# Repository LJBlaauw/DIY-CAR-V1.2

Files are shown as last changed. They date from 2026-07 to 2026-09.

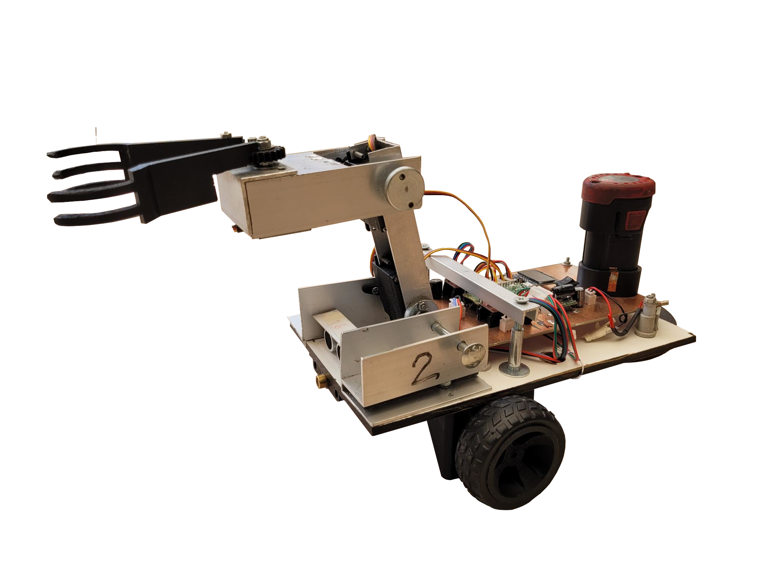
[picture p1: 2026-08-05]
hardware/Robot_carv1.1.png

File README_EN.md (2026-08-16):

# DIY Robot CAR

**This project started with my brother-in-law's idea to make a robot cart**
I have a background in electronics development (microcontrollers, power electronics and audio).
This was unknown territory for my brother-in-law, so as often happens, I offered my help.
Open source software was used for development. As OS I used Linux Fedora 44 desktop KDE plasma.
The challenge is to have the cart carry out these actions autonomously, especially the real-time nature of this is a challenge.
First we built everything on a breadboard. This was not very successful because the wiring often did not provide reliable connections.
Also the choice of the type of stepper motor (unipolar) and servos was inadequate (too light, too much mechanical play)
So version zero has been updated to version 1 with bipolar stepper motors and drivers, MG996 servos with metal gears.
To assemble this, various parts were 3D printed.
In version 1, most of the mechanics were made of sheet material and aluminum profiles.
In version 2 an electronic compass and acceleration sensor have been added. The gripper has also been fundamentally changed and has been 3D printed as much as possible.

The first questions that had to be answered were:
1. What is the scope of the project (what should the robot cart do)
2. What is readily available online
3. What materials are we going to use (motors and sensors)
4. What kind of software are we going to use to make the control possible.
5. presentation of status and measurement data
6. Develop tools and environment
 
1. **Scope: The robot cart must autonomously search for a light source and pick up an object there and bring it to the starting point**

2. **availability:**
1. We could find everything at various hobby stores, Amazon and Aliexpress.
 
3. **Materials**
1. *Motors:*
1. Two independently controllable stepper motors for locomotion.
2. Three independently controllable servo motors for the robot arm and gripper.
*Sensors:*
1. Ultrasonic sensor to measure the distance from the cart to the object.
2. Two light sensitive resistors to find the direction of the light source.
3. We chose the RP2040 of Raspberry Pi as the microcontroller, in version 2 the RP2350W.
4. Optional compass/acceleration sensor.
5. Optionally a WiFi connection with a web socket to read sensor data and issue commands.
    
4. **Programming language**
For the programming language we chose Micropython, which is easier to learn than C/C++.
The advantage is that no translation is required and many ready-made library components are built-in.
To get a good real-time working system there are a number of challenges.
Since Micropython is an interpreter, it runs a factor of 100 slower than C.
There are a number of options to optimize the real-time properties.
1. Using the PIO state machines integrated into the microcontroller.
2. Divide the Software modules (workload) over the two CPU cores
3. Possibly use cooperative multitasking (asyncio).
    
5. **Presentation**
As a presentation, we have a multi-color LED and an OLED display of 128x64 dots as a status message.
With version two we opted for the RP2350W. This has 2 M33 instead of the M0 cores.
With this processor update, calculating the compass/gear is much faster, and
remote control/reading is also possible with a web socket.
There are also two LEDs that signal 5V and 3.3V.
The REPL of the IDE tools is also present to display information with print commands.
    
6. **Development tools**
To design and produce the printed circuit board for electronics I use:
1. Schematic and layout: KiCAD (now version 10.4), FlatCAM Gerber to Gcode, CNC machine an upgraded 3018 with GRBLHAL controller.
2. Mechanical design: FreeCAD for 3D parametric models and a Prusa MK4 3D printer.
3. Software development environment: IDE VSCODE with micropico extension and AI claude 4.6 chat.
4. Thonny IDE simpler development environment than VSCODE.

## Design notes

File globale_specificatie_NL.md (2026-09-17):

# DIY Robot Car — MicroPython op RP2350 (Pico 2 W)

## Systeembeschrijving

Een autonoom rijdend robotkarretje dat een lichtbron opzoekt, ernaartoe rijdt, met een grijparm een voorwerp oppakt en daarna naar de beginpositie terugkeert.

### Status van waarden

In dit document worden ontwerpwaarden waar nodig als volgt aangeduid:

- **[GEMETEN]** — rechtstreeks op de huidige robot/hardware gemeten.
- **[BEREKEND]** — afgeleid uit gemeten waarden, datasheetwaarden of softwareconstanten.
- **[AANNAME]** — gebruikt in het ontwerpmodel, maar nog niet voldoende gemeten.
- **[TE VERIFIËREN]** — hardware- of softwaregedrag dat nog expliciet getest moet worden.

Een hoge numerieke resolutie is niet automatisch dezelfde grootheid als fysieke nauwkeurigheid. Wielslip, bandvervorming, sensorbias, mechanische speling en kalibratie blijven afzonderlijke foutbronnen.

### Werkvolgorde

1. **LDR-scan** — Draai in één richting een volledige omwenteling + overlap (**370°**) en meet lichtsterkte met twee gepaarde LDR's. Een volledige omwenteling bevat altijd het maximum; de 10° overlap voorkomt dat een piek rond 0°/360° op de rand valt. Er is dus géén pre-roll (terugdraaien vóór de scan) meer nodig.
2. **Uitlijnen** — Draai naar de gevonden richting via de **kortste weg** (door- of terugdraaien, afhankelijk van welke hoek kleiner is). De laatste graden worden altijd in dezelfde richting benaderd zodat de speling/backlash constant blijft. De eindpositie wordt closed-loop bijgeregeld via de LDR's (zie hieronder). Daarmee worden hoek-/uitlijnfouten door gemiste stappen of mechanische afwijking gecorrigeerd; dit is geen detectie of correctie van algemene lineaire wielslip.
3. **Rijden met LDR-correctie** — Rij naar de lichtbron en corrigeer onderweg continu op koersafwijking: zolang er een verschil tussen de twee LDR-waarden (na gain-correctie) optreedt, stuurt de kar bij richting de helderste kant tot A ≈ B. Stop op ingestelde afstand via de ultrasoonsensor (draait onafhankelijk in de achtergrond, SM4).
4. **Grijpen** — Bestuur twee scharnier-servo's zodat de arm het voorwerp bereikt.
5. **Sluiten grijper** — Servo 4 met stroombeperking (PI-limiter) zodat de servo niet overbelast raakt.
6. **Terugkeren** — Omdraaien en via opgeslagen wielodometrie/trajectinformatie terug naar de startpositie; voorwerp neerzetten. De nauwkeurigheid hiervan wordt begrensd door cumulatieve odometriefout en wielslip.
7. **GY9250-ondersteuning** — gyro en magnetometer kunnen de oriëntatie/koers ondersteunen. Ze leveren geen absolute X/Y-positie. Software is aanwezig, maar integratie en hardwarekalibratie zijn nog niet gevalideerd.

---

## Hardware

| Component | Aantal | Type | Aansluiting |
|---|---|---|---|
| Stappenmotor | 2 | — | Driver: TMC2209 |
| Servomotor (arm) | 2 | MG996R | GPIO2, GPIO3 |
| Servomotor (grijper) | 1 | MG996R | GPIO22 — met stroomsensor |
| Servomotor (optioneel/reserve) | 1 | MG996R | GPIO4 — bedraad op PCB, nog niet aangesloten/geïmplementeerd |
| Ultrasoonsensor | 1 | RCWL-1601 | GPIO19 (Echo), GPIO20 (Trig) |
| LDR | 2 | 10 kΩ spanningsdeler (pull-up naar 3V3) | GPIO26, GPIO27 |
| Laser (kruishaar) | 1 | — | GPIO15 via MOSFET |
| OLED | 1 | SSD1306 | I2C0: SDA=GPIO0, SCL=GPIO1 |
| Gyroscoop/kompas | 1 | GY9250 | I2C1: SDA=GPIO10, SCL=GPIO11 — *software aanwezig (`lib/GY9250`, fusie, stepper-koppeling); integratie en hardwarekalibratie nog niet gevalideerd* |
| Stroomsensor grijper | — | 0,1 Ω shunt + opamp (gain 14×) | ADC2 = GPIO28 |
| LED | 1 | WS2812B | GPIO6 |
| WiFi/Bluetooth | 1 | Infineon CYW43439 (onboard Pico 2 W) | interne boardverbinding |

De robotcontroller is een **Raspberry Pi Pico 2 W** met een **RP2350** microcontroller en een onboard **Infineon CYW43439** wireless controller. In MicroPython wordt deze via de CYW43-driver aangestuurd. De webserver/websocket-besturing gebruikt WiFi; de geplande softwarearchitectuur houdt netwerk- en hoofdcontroltaken op core 0 en reserveert core 1 voor GY9250/displaytaken. Deze coreverdeling moet nog als geheel op hardware worden gevalideerd.

Zie [hardware/gpio_pinout.md](hardware/gpio_pinout.md) voor de volledige GPIO-tabel en verificatiestatus.

### Ontwikkelomgeving

| Onderdeel | Configuratie |
|---|---|
| Robotboard | Raspberry Pi Pico 2 W |
| Microcontroller | RP2350 |
| Robotfirmware | MicroPython voor Pico 2 W — **exacte versie/build nog vastleggen** |
| Ontwikkel-PC | Fedora Linux 44 |
| Desktop | KDE Plasma |
| PC-tests | CPython; pure-Python tests uit `tests/` |
| Hardwarevalidatie | logic analyzer voor PIO/STEP-timing; multimeter/meetopstelling voor voeding en sensorkalibratie |

> **[TE VERIFIËREN] Reproduceerbaarheid:** leg vóór de definitieve hardwaretest de exacte MicroPython-versie/build en de gebruikte CPython-versie vast. De software gebruikt RP2350-specifieke voorzieningen zoals PIO2 en `rp2.DMA()`.

---

## Software modules

### PIO State Machine toewijzing

| SM | Module | Functie |
|---|---|---|
| SM0 | stepper/stepper.py *of* stepper_ramp.py | Stapgenerator motor A |
| SM1 | stepper/stepper.py *of* stepper_ramp.py | Stapgenerator motor B |
| SM2 | stepper/stepper.py *of* stepper_ramp.py | Stapenteller motor A |
| SM3 | stepper/stepper.py *of* stepper_ramp.py | Stapenteller motor B |
| SM4 | ultrasoon/ultrasoon.py | Ultrasoonsensor trigger + echometing |
| SM8 | LDR/ldr_scan_isr.py | Variabele klok voor LDR-sampletiming (PIO2 SM0) |

PIO0 is hiermee vol (4 van 4 SM's). `stepper.py` en `stepper_ramp.py` zijn **alternatieven** — ze claimen dezelfde SM's en dezelfde GPIO's, dus importeer er altijd maar één.

### DMA-kanaaltoewijzing

| Kanaal | Module | Functie |
|---|---|---|
| 2 stuks (dynamisch geclaimd via `rp2.DMA()`) | stepper/stepper_ramp.py | Rampatabel → TX-FIFO van SM0 / SM1 |

De RP2350 heeft 16 DMA-kanalen; `treq_sel = (pio_num << 3) + sm_num` (klopt ook op RP2350, `DREQ_PIO2_TX0 = 16`).

---

### `lib/stepper/stepper.py`

Dual stappenmotor controller op basis van PIO. Beide motoren lopen onafhankelijk via eigen SM en teller-SM.

**Constanten:**
- **[GEMETEN]** `WHEEL_CIRC = 19,1 cm` — wielomtrek. Was 20,94 cm; die waarde gaf **8,8 % te korte afstanden** (50 cm gecommandeerd → 45,6 cm gereden). De belaste rolomtrek van een rubberwiel is iets kleiner dan de vrije omtrek, dus deze waarde nog kalibreren (zie *Odometriekalibratie* hieronder).
- **[GEMETEN]** `TRACK_WIDTH = 13,6 cm` — geometrische spoorbreedte hart-op-hart. Nodig voor elke rotatie- en koersberekening.
- `STEPS_REV = 12800` — stappen per omwenteling (**1/64 microstepping**, TMC2209: 200 volle stappen × 64). MS-pinnen hardwired: **MS1 → GND, MS2 → VCC_IO** *(in de huidige documentatie als +5 V aangegeven; fysiek verifiëren)* (zie [hardware/gpio_pinout.md](hardware/gpio_pinout.md)).
- **[BEREKEND]** `CM_PER_STEP ≈ 14,9 µm/stap`
- **[BEREKEND]** `STEPS_PER_DEG ≈ 159` — stappenverschil tussen de wielen per graad koersverandering. Resolutie dus **0,0063°**.
- **[BEREKEND/CONFIG]** `F_PIO = 15 MHz` — 150 MHz sysclk / 10, dus een **integer klokdeler** (geen jitter van de fractionele deler). `speed_to_delay()` geeft bij de topsnelheid van 12800 stappen/s de waarde **576**. De delaylus van déze PIO is twee instructies (`nop().side(0)` + `jmp(y_dec)`), dus elke eenheid is 2 cycles en de **snelheidsresolutie is 0,17 %**. De STEP-puls blijft 11 cycles = **733 ns**, ruim boven het TMC2209-minimum van ~100 ns.
  > De vaak genoemde 1167 cycles en 0,085 % horen **niet** hier maar bij `_delay_for()` in `stepper_ramp.py`, waar de delaylus één cycle per eenheid is. Verwissel die twee niet.

> **`OVERHEAD` in `speed_to_delay()`:** blijft op de op hardware gemeten 9. De PIO-lus kost werkelijk 13 cycles vaste overhead terwijl de formule er 18 aanneemt; bij 15 MHz zakt die **systematische** afwijking bij topsnelheid automatisch van ~2,3 % naar ~0,43 %, dus hermeten is niet meer nodig. (Eerder stond hier ~11 %; dat was te hoog ingeschat.) Daar komt nog de afkapping van `int()` bij, maximaal 2 cycles ≈ 0,17 %.

**Publieke functies:**

| Functie | Beschrijving |
|---|---|
| `mov(dir, speed, dist)` | Beide motoren gelijktijdig. `dir='f'/'b'`, speed in cm/s, dist in cm |
| `s1(dir, speed, dist)` | Alleen motor A |
| `s2(dir, speed, dist)` | Alleen motor B |
| `rotate(dir, speed, dist)` | Draai op de as. `dir='l'/'r'`, dist in cm (booglengte wiel) |
| `stop()` | Stop beide SM's direct |
| `enable()` / `disable()` | Zet driver-enable aan/uit |
| `status()` | Print positie en status van beide motoren |
| `distance()` | Print en geef PIO-stapafstand terug (cm) |
| `reset_PIO_distance()` | Reset hardware-tellers naar nul |
| `pio_pos1()` / `pio_pos2()` | Lees aantal stapjes motor A/B uit PIO |

**Werking stapgenerator (PIO):**
- `pull(noblock)` haalt een delay-waarde uit de TX FIFO (of hergebruikt de vorige).
- De delay bepaalt de stapfrequentie → snelheid.
- De teller-SM telt STEP-flanken en genereert een IRQ als het doel bereikt is.
- IRQ-handler stopt de bijbehorende motor-SM en werkt de softwarepositie bij.

**Beperking:** er is geen ramp. De snelheid wordt in één keer gecommandeerd, dus vanuit stilstand moet de rotor binnen één microstap (78 µs) naar de eindsnelheid springen. Dat is een oneindige versnelling: de rotor kan het veld niet volgen, verliest synchronisme en de motor blijft zoemend staan. Dit is een **synchronisme-fout, geen koppel-fout** — zie de koppelbegroting hieronder. `stepper_ramp.py` of `stepper_rmp.py`lost dit op.

---

### `lib/stepper/stepper_rmp.py`

Dual stappenmotor controller **met ramp** (PIO + DMA) zelfde functie als `stepper.py` maar nu met ramp.

### `lib/stepper/stepper_ramp.py`

Dual stappenmotor controller **met ramp** (PIO + DMA) en doorlopende koerscorrectie. Vervangt `stepper.py`.

Het is een **API-grotendeels compatibele opvolger, geen drop-in replacement.** De namen `mov`, `s1`, `s2`, `rotate`, `stop`, `enable`, `disable`, `status`, `distance`, `pio_pos1/2` en `reset_PIO_distance` bestaan nog met dezelfde betekenis, maar bij migratie zijn dit de breekpunten:

| Verschil | Gevolg |
|---|---|
| Geen globale `sm0`..`sm3` meer | code die daar direct aan komt, breekt |
| De generator-SM's blijven **permanent actief** en stallen op een lege FIFO | wachten op `sm0.active()` werkt niet meer; gebruik `busy()` |
| `distance()` print niets en geeft **één signed middenafstand** i.p.v. twee motorafstanden | aanroepers die twee waarden uitpakken, breken |
| De bewegingsfuncties geven `True`/`False` i.p.v. impliciet `None` | alleen relevant als de returnwaarde gebruikt werd |
| Andere stop- en voltooiingssemantiek | `halt()` / `brake()` / `emergency_stop()` zijn nu drie verschillende dingen |
| `reset_PIO_distance()` weigert tijdens een beweging | roep eerst `halt()` of `brake()` aan |
| Ongeldige invoer geeft `ValueError` i.p.v. stil door te rekenen | een negatieve `dist` werd eerder stil positief gemaakt |

#### Ontwerpbasis

| Grootheid | Waarde |
|---|---|
| Massa kar | **[GEMETEN]** 1636 g |
| Wielomtrek / -radius | **[GEMETEN/BEREKEND]** 19,1 cm / 3,04 cm |
| Spoorbreedte (hart-op-hart) | **[GEMETEN]** 13,6 cm geometrisch |
| Motor | 17HS8401 — NEMA 17, 1,7 A, 52 N·cm, 1,8 Ω, 3,2 mH, rotor 68 g·cm² |
| Driver | TMC2209, standalone, **stealthChop**, 1/64 microstepping |
| VREF / motorstroom | **[BEREKEND, TE VERIFIËREN]** 1,0 V → ca. **0,71 A RMS** volgens huidige driveraannames; controleer sense-resistor/driveruitvoering |
| Motorspanning | 24 V (6S Li-ion, 25,2 V vol → ~18 V leeg) |
| Bereik snelheid | **[ONTWERPWAARDE, TE VERIFIËREN]** start 0,1 omw/s = 1,91 cm/s · max 1,0 omw/s = 19,1 cm/s |

**Koppelbegroting [BEREKEND]** — deze begroting ondersteunt de keuze voor een ramp en laat op papier ruime koppelmarge zien; de werkelijke marge moet met de huidige motorstroom en belasting op hardware worden bevestigd:

| Post | Koppel per wiel |
|---|---|
| Versnellen van 1636 g bij 55 cm/s² | 1,37 N·cm |
| Rotor-inertie (68 g·cm²) | 0,013 N·cm |
| Rolweerstand (ruim geschat) | ~1,2 N·cm |
| **Totaal nodig** | **~2,6 N·cm** |
| **Beschikbaar bij VREF 1 V** | **~22 N·cm** → factor 8 marge |

De post "versnellen" is `m·a/2 × r` = 1,636 kg × 0,55 m/s² ÷ 2 wielen × 0,0304 m; de eigen traagheid van de wielen zit er nog niet in, maar die is bij deze marge niet interessant.

Bij 22 N·cm en wielradius 3,04 cm is de trekkracht 7,2 N per wiel (14,5 N totaal) tegen een gewicht van 16,1 N: de **wielen slippen eerder dan dat de motor koppel tekortkomt**. Daarom is VREF = 1,0 V voorlopig een passende ontwerpinstelling (1,8 W dissipatie i.p.v. 10,4 W bij vol stroom). stealthChop volstaat: het praktische plafond is ~300 rpm en de kar draait op 60 rpm. De SPREAD-pin hoeft niet verbonden te worden.

#### FIFO-woordformaat

Elk 32-bit woord in de TX-FIFO codeert een heel **segment** in plaats van één stap:

| Bits | Inhoud |
|---|---|
| 15..0 | aantal stappen in dit segment − 1 (max 65536) |
| 31..16 | delay per stap in PIO-cycles (max 65535) |

Daardoor kost een ramp van 2200 stappen maar 256 woorden = **1 kB**. Eén 32-bit woord per stap zou 2200 × 4 = **8800 bytes ≈ 8,6 KiB per ramp** kosten. Vier losse tabellen (op/af voor twee motoren) zouden samen ongeveer **34,4 KiB** vragen, exclusief Python-objectoverhead. Segmentcodering reduceert dit sterk. Een kruisfase tot **97,8 cm** past in één enkel woord.

De PIO-lus is 7 instructies; vaste overhead **5 cycles per stap** (0,43 % bij topsnelheid).

#### Fasen van een beweging

| Fase | Bron | CPU-kosten |
|---|---|---|
| Ramp op | DMA-tabel, 256 woorden | **0** — segmenten van ~2 ms zijn te snel voor MicroPython; DMA is hier vereist en immuun voor GC-pauzes |
| Kruisfase **zonder** bijsturing | zelfde DMA-transfer, 1 woord | **0** |
| Kruisfase **met** bijsturing | CPU pusht 1 woord per 20 ms per motor | ~0,1 % (≈100 `put()`/s) |
| Ramp af | DMA-tabel, 256 woorden | **0** |

Een complete beweging van 50 cm zonder bijsturing is **513 woorden = 2052 bytes in één DMA-transfer** — hetzelfde nul-overhead gedrag als het oude concept, mét ramp. Er is daarbij **geen interrupt**: `stepper_ramp.py` configureert nergens een DMA- of PIO-IRQ. Tijdens de uitvoering doet de CPU niets, en voltooiing wordt gepolld met `busy()`. (De oude `stepper.py` hierboven had wél `sm2.irq`/`sm3.irq`.)

**Bij een lege FIFO stalt `pull(block)` met STEP laag.** Gevolgen:
- de motor houdt zijn positie, er gaat geen stap verloren;
- CPU-latency (ook een GC-pauze van tientallen ms) beïnvloedt de **staptiming niet** — de PIO genereert met hardware-precisie. Te late CPU betekent dat de correctie één slice later komt, geen timingfout;
- loopt de FIFO écht leeg, dan is het gevolg een korte pauze, geen glitch. Dit is netjes degraderend faalgedrag, in tegenstelling tot een CPU-getimede pulsgenerator.

Met 3 slices vooruit in de FIFO is de runway **60 ms** en de regellatentie eveneens ≤60 ms.

**DMA en CPU mogen nooit gelijktijdig in dezelfde FIFO schrijven** — de volgorde zou door elkaar lopen en de twee motoren konden verschillende segmentvolgordes krijgen, waarmee de ramp én de koers onbetrouwbaar worden. Daarom:

- tijdens de opramp pusht de CPU niets; `Move.service()` wacht tot `dma.active()` van **beide** motoren `False` is. De DMA is dan gestopt met *schrijven* terwijl de FIFO nog data bevat — precies de voorsprong die de CPU nodig heeft.
- de ramp-af-DMA wordt pas gestart nadat de CPU is gestopt met pushen.

> Wachten tot de rampstappen ook *uitgevoerd* zijn zou fout zijn: dan loopt de FIFO leeg en pauzeert de motor tussen ramp en kruisfase.

**Brugsegment.** Als de opramp-DMA klaar is met schrijven staan er nog maximaal 4 woorden in de FIFO. Aan het eind van de ramp zitten we op topsnelheid, dus die 4 woorden zijn samen maar ~3 ms — met `service()` elke 10 ms zou de FIFO alsnog leeglopen. Daarom eindigt de opramptabel met één **brugsegment** op kruissnelheid van `BRIDGE_SLICES × SLICE_MS` = 40 ms. Die stappen horen bij de kruisfase maar worden niet bijgestuurd; een correctie 40 ms eerder of later maakt niets uit.

**S-curve:** de snelheid volgt een smoothstep (3p²−2p³) in de afgelegde weg, dus de versnelling is nul aan begin én eind van de ramp — geen koppelschok op de overgangen. Kost niets extra, want de tabel wordt in Python gegenereerd en daarna alleen door DMA afgespeeld. `ACCEL_CM_S2 = 55` bepaalt de ramp-*afstand* (3,28 cm); de piekversnelling is 1,5× = 82 cm/s² = 0,084 g en de ramp *duurt* 0,55 s.

Een beweging korter dan 2 × 3,28 = 6,6 cm haalt de topsnelheid niet en krijgt automatisch een driehoekig profiel.

#### Exacte afstand

Bijsturen verandert **wanneer** stappen komen, niet **hoeveel**. Per motor wordt `committed` bijgehouden: de som van alle weggeschreven `repeat`-waarden. Het afremmpunt wordt op `committed` bepaald, niet op een gemeten positie, dus het **gecommandeerde gemiddelde stappentotaal is exact** — onafhankelijk van wanneer de regellus toevallig aanroept. De *fysieke* afstand is dat niet: microstepping-nauwkeurigheid, wielslip, bandvervorming en de kalibratie van `WHEEL_CIRC` komen daar nog overheen. Per slice geldt `repeat_A + repeat_B = 2 × base`, waardoor het midden van de kar precies `base` stappen opschuift terwijl het verschil de koers verandert.

Beide motoren krijgen per slice dezelfde slice-**duur** (20 ms) en een verschillend stappenaantal; daardoor blijven ze in de tijd synchroon (**berekende** afrondingsfout < 20 µs op 20 ms; nog niet met een logic analyzer nagemeten).

#### Odometrie — signed, want de teller-SM kent de DIR-pin niet

De teller-SM's tellen **STEP-flanken** en weten niets van de richting. Een ruwe pulsteller is daarom géén positie: bij een rotatie op de plaats lopen beide tellers positief op terwijl de wielen tegengesteld draaien. Elke motor houdt daarom naast de monotone pulsteller een **signed positie** bij die bij elke richtingswisseling het teken meeneemt.

| Functie | Betekenis |
|---|---|
| `pio_pos1()` / `pio_pos2()` | monotone pulsteller (ongesigneerd), gebruikt door `busy()` |
| `_Motor.travel()` | signed positie in stappen: vooruit positief, achteruit negatief |
| `distance()` | `(travel_A + travel_B) / 2 × CM_PER_STEP` — een rotatie geeft ~0 cm, achteruit telt negatief |
| `heading()` | `(travel_A − travel_B) / STEPS_PER_DEG` — werkt ook bij een rotatie op de plaats |

> **Let op:** de tellers tellen STEP-pulsen/commando's, geen gegarandeerde fysieke wielverplaatsing. Bij slip of een gemiste motorstap kan de odometrie dus afwijken. De GY9250 levert een onafhankelijke meting van draaisnelheid en oriëntatie, maar geen absolute lineaire X/Y-positie; lineaire slip van beide wielen vraagt een externe positiereferentie om rechtstreeks te detecteren.

#### Koerscorrectie — cascade LDR + gyro

Koersverandering komt van een **verschil in stappenaantal** tussen de wielen. Bij fire-and-forget, waar beide motoren aan hetzelfde totaal vastzitten, geeft een snelheidsverschil netto **nul** koersverandering (de kar maakt een boog en komt in dezelfde richting terug). In de kruisfase ligt dat totaal niet vast, dus daar integreert een snelheidsverschil wél tot een blijvende koersverandering.

| Lus | Sensor | Frequentie | Rol |
|---|---|---|---|
| Buiten | LDR A/B-verschil | enkele Hz (1× per 5 slices) | bepaalt **waar** we heen moeten; A ≈ B = recht op de bron. Levert het setpoint voor de draaisnelheid |
| Binnen | GY9250 gyro-Z | elke slice (~50 Hz) | onderdrukt **storingen**: hobbels, gleuven, ongelijke vloer, wielslip. Regelt het verschil tussen gewenste en gemeten draaisnelheid weg |

Dit is **geen dubbele besturing**: de LDR bepaalt de richting, de gyro alleen de storingsonderdrukking.

Let op wat de binnenlus wél en niet doet. Hij regelt het verschil tussen gewenste en gemeten **draaisnelheid** weg, dus hij dempt een verstoring *zolang die plaatsvindt*. Hij integreert geen hoekfout, dus de verdraaiing die er onderaan de streep uit komt wordt daarna niet teruggedraaid; de LDR-buitenlus doet dat. Zonder LDR (`damp_yaw_rate()`) is er dus **geen koershouden** — alleen demping, met bovendien blijvende drift door gyrobias. Bij een kortdurend afgedekte lichtbron blijft de kar daarom ongeveer rechtdoor gaan, maar hij komt niet op de oude koers terug.

De **magnetometer/kompas** wordt tijdens het rijden expres níet gebruikt — de stappenmotoren verstoren het veld (zie de GY9250-stappenmotorkalibratie). Het kompas is voor de terugweg, waar een absolute koers nodig is.

De **acceleratiemeter** wordt níet voor slipdetectie gebruikt. Dat idee — "stappen zonder versnelling betekent slip" — werkt niet: bij constante snelheid is de voorwaartse versnelling per definitie nul, dus normaal rijden en volledig doorslippen zien er identiek uit.

Wat er wél in zit is een **koersvolgfout** op gyro-Z: wijkt de gemeten draaisnelheid aanhoudend af van wat er werkelijk is weggeschreven, dan staat `HeadingController.yaw_tracking_error` op `True`. Dat is een *aanwijzing*, geen slipbewijs — regeldynamiek, gyrovertraging, verzadiging en een verkeerde gain geven hetzelfde beeld. Lineaire slip (beide wielen recht vooruit) is er sowieso niet mee te zien; dat vraagt een externe positiereferentie.

**Stuurgezag:** bij een snelheidsdifferentie van ±20 % is de draaisnelheid ±32 °/s; bij ±5 % is dat ±8 °/s. Resolutie 0,0063° (1 stap verschil). Die 32 °/s geldt **bij topsnelheid**: het gezag is een fractie van de rijsnelheid en schaalt dus evenredig mee (bij 5 cm/s nog 8,4 °/s). `turn_authority_deg_s(rate)` rekent dat uit en `Move()` zet er het plafond van de `HeadingController` mee.

#### Waarom niet de PIO-klok variëren

Het alternatief — `SMn_CLKDIV` tijdens runtime wijzigen — is bewust **niet** gebruikt, ook al is het technisch mogelijk via `machine.mem32`:
- het zit buiten het datapad, dus niet synchroon met de segmentgrenzen;
- de stappenaantallen zijn dan niet meer exact bekend;
- de delay-waarden staan in PIO-cycles, dus een klokwijziging herschaalt de rampatabel onderweg (en de versnelling schaalt met f²).

Als globale **snelheids-override** (alles langzamer, bv. bij een obstakel) blijft de klokdeler wel bruikbaar.

#### Publieke API

| Functie | Beschrijving |
|---|---|
| `mov(dir, speed, dist)` | Beide motoren, fire-and-forget mét ramp, nul CPU-overhead |
| `s1(dir, speed, dist)` / `s2(...)` | Idem, één motor |
| `rotate(dir, speed, dist)` | Draai op de as, `dist` = booglengte per wiel in cm |
| `rotate_deg(graden, speed)` | Draai op de as over een hoek. Positief = rechts |
| `drive(dist, speed, correction=fn)` | Beweging **met** doorlopende bijsturing; geeft een `Move` terug |
| `adrive(...)` | asyncio-variant van `drive()` |
| `Move.service()` | Vul de FIFO's bij en pas de correctie toe. ≥1× per 10 ms aanroepen. `False` = klaar |
| `Move.finish()` | Breek de beweging af en rem netjes af — ook tijdens de opramp, waar eerst de lopende DMA transactioneel wordt gewist en daarna vanaf de wérkelijke snelheid wordt afgeremd |
| `HeadingController(ldr_diff, gyro_rate)` | Cascade-koersregelaar. Geef de **controller zelf** mee aan `correction=`: dan zet `Move()` zijn stuurgezag op de werkelijke rijsnelheid en krijgt hij terugkoppeling over wat er is weggeschreven |
| `gyro_z_deg_s(sensor, sign=None)` | **Vereist** rond de GY9250: de driver levert radialen/s, de regelaar rekent in graden/s. Past `GYRO_Z_SIGN` toe |
| `damp_yaw_rate(gyro_rate)` | Demping van de draaisnelheid op alleen de gyro. **Houdt geen koers vast** — heette daarom eerder ten onrechte `hold_heading()`; zie de cascade-uitleg hierboven |
| `turn_authority_deg_s(rate)` | Maximale draaisnelheid bij een gegeven rijsnelheid |
| `halt()` (= `stop()`) | Onmiddellijke stop, drivers blijven **aan**: de motoren houden hun positie. Dit is het gedrag van `stepper.stop()` |
| `brake()` | Nette stop: remt af vanaf de **geschatte** huidige snelheid (uit de voortgang door het profiel) |
| `emergency_stop()` | Noodstop: drivers **uit**, DMA stil, FIFO's leeg. Motoren lopen vrij, de kar kan doorrollen |
| `distance()` / `heading()` | Signed odometrie uit de hardware-tellers. `heading()` is positief naar rechts, hetzelfde teken als `rotate_deg()` en als de bijsturing |
| `creep(dist, speed)` | Kleine correctiebeweging; de enige functie met een **signed** afstand |
| `busy()` | True zolang niet alle weggeschreven stappen uitgestuurd zijn |
| `stopping_distance_cm(speed)` | Afstand die de kar ná `finish()` nog aflegt: afremramp + wat al in de FIFO's staat |
| `info()` | Print alle afgeleide ontwerpgetallen (geen hardware nodig) |
| `meet_frequentie()` | Meet de werkelijke STEP-frequentie tegen `_delay_for()`, om `CYCLES_FIXED` te verifiëren |

**Op tijd beginnen met afremmen.** `finish()` stopt niet onmiddellijk — de afremramp en de al weggeschreven slices liggen vast:

| Snelheid | afremramp | in FIFO | **committed** | + ultrasoonlatentie (50 ms) |
|---|---|---|---|---|
| 19,1 cm/s | 3,28 cm | 1,15 cm | **4,43 cm** | 0,96 cm |
| 10 cm/s | 0,88 cm | 0,60 cm | **1,48 cm** | 0,50 cm |
| 5 cm/s | 0,19 cm | 0,30 cm | **0,49 cm** | 0,25 cm |

```python
doel = approach.brake_target_cm(snelheid)   # lib/gripper/approach.py
cm, kind = ultrasoon.read_cm()
if kind == 'ok' and cm <= doel:
    mv.finish()
```

Rem daarom voor de laatste ~25 cm af naar 5 cm/s: dat brengt de stoponzekerheid van 5,4 cm naar 0,74 cm, en dat is robuuster dan proberen 4,43 cm exact te voorspellen.

> Een volledige stap-voor-stap uitleg van de PIO/DMA/FIFO-werking en van het sturen staat in [stepper_ramp.md](stepper_ramp.md).

Ongeldige invoer wordt geweigerd met `ValueError` (onbekende richting, snelheid ≤ 0, acceleratie ≤ 0, niet-eindige getallen). Een nulafstand geeft `False` terug zonder de hardware aan te raken — een DMA-transfer met `count=0` is firmware-afhankelijk gedrag en wordt vermeden. Een nieuw commando **overschrijft** een lopende beweging (er wordt niet geblokkeerd tot die klaar is).

Een gevraagde snelheid onder `V_START_CM_S` wordt gerespecteerd en levert géén ramp op: de startsnelheid is een *bovengrens* voor veilig starten, niet een minimum.

#### Kentallen

| | |
|---|---|
| Topsnelheid 12800 stappen/s | delay 1167 cycles, resolutie 0,085 % |
| Startsnelheid 1280 stappen/s | delay 11714 cycles |
| Ramp | 2200 stappen = 3,28 cm, 256 segmenten, max snelheidssprong 1,78 % per segment |
| Kruis-slice | 20 ms = 256 stappen |
| 360° op de plaats | 28632 stappen per wiel = 2,24 wielomwentelingen = 2,24 s bij 1 omw/s |
| Noodstop | `ENA` hoog + `dma.active(0)` + `sm.init()` om de FIFO te wissen |

#### Odometriekalibratie (nog uit te voeren)

Twee kalibraties, in te passen in de kalibratiesessie. Zonder deze stuurt de kar structureel scheef, hoe goed de ramp ook is:

1. **Afstandsschaal** — rijd een opgemeten 1,00 m, meet de werkelijk afgelegde afstand, corrigeer `WHEEL_CIRC`. Vangt zowel de resterende meetfout als de belaste rolomtrek.
2. **Rotatieschaal** — commandeer exact 360° (28632 stappen per wiel, tegengesteld), meet de resthoek met de GY9250, corrigeer `TRACK_WIDTH`. De effectieve spoorbreedte is door tyre-scrub meestal 1–5 % groter dan de geometrische 136 mm.

#### Koersvolgfout (voorheen "slipdetectie")

`HeadingController.yaw_tracking_error` wordt gezet als de **gemeten** draaisnelheid aanhoudend (10 ticks) meer dan 8 °/s afwijkt van de draaisnelheid die er **werkelijk is weggeschreven**.

Twee dingen daarbij, waar dit eerder misging:

- **Vergelijk met wat er echt gebeurd is, niet met het setpoint.** Het stuurgezag is een fractie van de rijsnelheid, dus bij lage snelheid is er veel minder gezag dan de ±32 °/s bij topsnelheid. Werd er tegen het geklemde setpoint vergeleken, dan kon de regelaar 25 °/s "commanderen" terwijl de wielen er fysiek maar ~8 °/s konden leveren — en dat verschil las als slip. `Move()` zet daarom het plafond op `turn_authority_deg_s(r1)` en meldt via `note_applied()` terug wat er na afronden en aftoppen echt is weggeschreven.
- **Een afwijking is geen slipbewijs.** Regeldynamiek, gyrovertraging, verzadiging en een verkeerd afgestelde gain geven exact hetzelfde beeld. De vlag heet daarom `yaw_tracking_error` en niet `slipping`.

> Wat níet werkt: "motor actief + weinig voorwaartse versnelling". Bij constante snelheid is de voorwaartse versnelling immers nul, dus die test zou de hele kruisfase als slip melden. **Lineaire** slip (beide wielen slippen recht vooruit) is met wielodometrie en een IMU principieel niet te zien; daarvoor is een externe positiereferentie nodig.

#### Tests

[`tests/test_stepper_ramp_math.py`](tests/test_stepper_ramp_math.py) — **226 pure-Python tests, geen hardware nodig** (`machine` en `rp2` worden gestubd, draait ook op de PC met CPython):

```
python3 tests/test_stepper_ramp_math.py
```

Gedekt: exact stappentotaal van `ramp_words()` / `cruise_words()` / `profile_words()` over het hele afstandsbereik (0 t/m 200 000 stappen), monotone snelheid in beide ramprichtingen, delay- en repeat-velden binnen bereik, driehoeksprofiel, nulafstanden, invoervalidatie, de slice-rekenkunde (gelijke duur, exact midden), de signed odometrie bij rotatie en achteruit, `Move.finish()`, en de DMA → CPU overgang (dat de CPU niet pusht zolang de DMA nog schrijft).

Als regressie ook de drie toestandsfouten die hierin zaten: `finish()` tijdens de opramp-DMA (waarbij `busy()` eeuwig `True` bleef), een nieuw commando tijdens een lopende beweging (DIR en tellers gingen om zonder eerst te stoppen), en de tekenconventie (`rotate_deg(+90)` gaf `heading() = −90`).

[`tests/test_gripper_geometry.py`](tests/test_gripper_geometry.py) — 32 tests voor de grijpergeometrie, eveneens zonder hardware.

#### Nog te verifiëren op hardware

- **Drie losse tekenconventies.** Ze corrigeren verschillende fouten en horen dus niet in één constante — een omgekeerd gemonteerde GY9250 vraagt een ander gyroteken zonder dat er iets mankeert aan de motorbekabeling. Publiek geldt overal: **positief = naar rechts**.
  - `MOTOR_TURN_SIGN` (+1 / −1): welke fysieke motor links of rechts zit. Test: `rotate_deg(+90)` moet naar **rechts** draaien en `heading()` moet daarna ≈ +90 geven.
  - `GYRO_Z_SIGN` (+1 / −1): opgeheven wielen, draai de kar met de hand naar rechts — `gyro_z_deg_s(sensor)()` moet **positief** zijn.
  - `LDR_DIFF_SIGN` (+1 / −1): houd een lamp rechts van de kar — `ldr_diff()` moet **positief** zijn.
- `CYCLES_FIXED = 5`: de vaste PIO-cyclusoverhead **per stap binnen een segment** (`mov[2]` = 3, delaylus = delay + 1, `jmp(y_dec)` = 1). Daar komt per **segmentovergang** nog 4 cycles bij voor `pull`/`out`/`out`/`mov`, die niet in de formule zitten; de effectieve overhead is dus `5 + 4/repeat`. Bij de 256 rampsegmenten is dat 0,02 %, bij segmenten van 1 stap 0,4 %. De waarde is **berekend, nog niet gemeten**. `meet_frequentie()` vergelijkt de werkelijke STEP-frequentie met `_delay_for()`; meet zowel lange segmenten als segmenten van 1, 2, 8 en 256 stappen, en controleer met een **logic analyzer** ook de pulsbreedte (verwacht 200 ns) en of er stappen wegvallen.
- Maximale startsnelheid en maximale versnelling, met de GY9250 als onafhankelijke referentie (de PIO-teller kan een stall niet zien). De aangenomen 0,1 omw/s is conservatief — 20 volle stappen/s ligt ruim binnen het pull-in gebied van elke NEMA 17.
- Regelversterkingen `kp_ldr` en `kp_gyro`. De standaard `kp_ldr = 25` geeft bij een vol LDR-verschil 25 °/s, net onder het plafond van 32,2 °/s, dus de regelaar verzadigt normaal niet.
- `fifo_join=PIO.JOIN_TX` is **niet** gebruikt (niet geverifieerd in deze MicroPython-versie). Werkt het, dan verdubbelt de FIFO-runway van 60 naar 140 ms.

---

### `lib/servo/servo_crl.py`

`ServoController` klasse voor 3× MG996R servo (servo 1, 2, 4) + kruishaarlaser.

**Init:** `sc = ServoController()` — alle servo's gaan direct naar rustpositie.

**Rustposities (duty %):**

De definitieve rustposities worden automatisch of handmatig ingesteld en opgeslagen in `config.json`. De historische vaste waarden hieronder zijn alleen nog referentie.

<!-- Historisch, niet meer normatief:
| Servo | GPIO | Rust (duty%) | Functie |
|---|---|---|---|
| 1 | GPIO2 | 4,1% | Onderste scharnier arm |
| 2 | GPIO3 | 3,6% | Bovenste scharnier arm |
| 4 | GPIO22 | 2,0% | Grijper |
-->

| Servo | GPIO | Functie |
|---|---|---|
| 1 | GPIO2 | Onderste scharnier arm |
| 2 | GPIO3 | Bovenste scharnier arm |
| 4 | GPIO22 | Grijper |

**PWM-tick:** GPIO5 (INPUT) moet fysiek verbonden zijn met GPIO2 (servo1 PWM). De falling edge triggert de servo-update ISR @ 50 Hz.

**Publieke methoden:**

| Methode | Beschrijving |
|---|---|
| `servo_pos(nr, graden, graden_per_sec)` | Relatief t.o.v. rust (nooit onder rust). Voorbeeld: `servo_pos(1, 30)` → rust+30° |
| `servo_rest(nr=None)` | Terug naar rust. Zonder argument: volgorde 4→1→2 @ 20°/s |
| `set_rest_pct(nr, pct)` | Stel rustpositie in als duty-% |
| `servo_cur(mA, graden_per_sec)` | **SETPOINT-modus**: PI-regelaar houdt servo 4 op ingestelde stroom |
| `servo_cur_limit(mA)` | **LIMIT-modus**: positie is leidend, stroom wordt begrensd door PI-limiter |
| `update_cur_limit(mA, reset_integrator)` | Pas stroomlimiet aan tijdens runtime |
| `clear_cur_limit()` | Zet LIMIT-modus uit |
| `stop_cur()` | Zet SETPOINT-modus uit |
| `laser_power(percent)` | Laser duty-cycle 0–100% via MOSFET |
| `laser_off()` | Laser uit |
| `close()` | Deinit alle PWM en verwijder IRQ |

**Stroomregeling servo 4 (grijper):**
- Shunt: 0,1 Ω, opamp gain 14×, gemeten op ADC2 (GPIO28).
- EMA-filter (α=0,2) op de gemeten stroom.
- SETPOINT-modus: PI stuurt positie bij zodat stroom op setpoint blijft.
- LIMIT-modus: positie is leidend; PI-limiter trekt terug als stroom de limiet overschrijdt.

---

### `lib/ultrasoon/ultrasoon.py`

Ultrasoonsensor RCWL-1601 via PIO (SM4). Meet asynchroon in de achtergrond met ping-pong buffer.

**Config:**
- `PIO_FREQ_HZ = 2 MHz`
- `INTERVAL_MS = 50` — meetinterval
- `TIMEOUT_US = 30 000` — maximale echo-wachttijd (≈ 5 m)

**Publieke functies:**

| Functie | Retourwaarde | Beschrijving |
|---|---|---|
| `read_us()` | `(us, kind)` | kind: `'ok'`, `'timeout'`, `'overflow'` |
| `read_cm()` | `(cm, kind)` | Afstand in cm, afgerond op 0,1 cm |
| `stop()` | — | Stop de SM |

> **API-conventie:** `read_us()` en `read_cm()` retourneren altijd een tuple `(waarde, kind)`. Controleer `kind == 'ok'` voordat de waarde numeriek wordt gebruikt; bij `timeout` of `overflow` mag de afstand niet als geldig getal in de regelaar terechtkomen.

De ldr-scan routine gebruikt inmiddels een eigen PIO-blok (SM8, zie tabel hierboven) in plaats van hetzelfde blok als de ultrasoonsensor (SM4) — de RP2350 heeft 3 onafhankelijke PIO-blokken. Hiermee is het eerder gemelde PIO-conflict tussen ultrasoon en ldr-scan opgelost; SM4 hoeft niet meer gestopt te worden tijdens de LDR-scan.

---

### `lib/LDR/ldr_scan_isr.py`

LDR-scan module. Draait het karretje via `stepper.rotate()`, samples LDR A en B synchroon met een PIO-klok (SM8 / PIO2 SM0) via ISR.

**Status: bevat nog bekende fouten — in ontwikkeling.**

**Scan-algoritme (herzien):**

1. **Volledige-omwentelingsscan (370°).** Draai in één richting 370° en sample beide LDR's apart. Geen pre-roll/terugdraaien vooraf: een volle omwenteling bevat altijd het maximum en de 10° overlap houdt een piek rond 0°/360° van de rand af. De 0–10° regio komt twee keer in de buffer voor; `_find_peak` neemt de eerste (vroegste) index.
   - *Randvoorwaarde:* de kar moet vrij op zijn as kunnen draaien (differentieel, `WHEEL_BASE_CM`) zonder kabels die bij 360°+ mee-twisten.
2. **Grove piekbepaling per LDR.** De LDR's staan horizontaal uit elkaar, dus er ontstaan twee helderheidsmaxima; de richting van de bron ligt op het **kruispunt A ≈ B** (na gain-correctie), niet op het maximum van de som. Zie ook de "Rijden naar de lichtbron"-sectie.
3. **Kortste weg terug (idee 2).** Na 370° staat de kar op eindhoek 370°; naar piekhoek θ is terugdraaien `370 − θ` en doordraaien `(θ − 10) mod 360`. Kies de kleinste. Laat de laatste graden altijd in dezelfde richting eindigen (bv. altijd in scan-richting; bij terugdraaien iets voorbij en dan vooruit terug), zodat de backlash constant en kalibreerbaar is.
4. **Closed-loop eindpositie via null-seek A−B (idee 3).** Grof naar de verwachte piekpositie op stappen (open-loop), daarna in kleine stapjes bijregelen met `measure_now()`. Gebruik hierbij **niet** de opgeslagen maximum-magnitude als drempel (de bewegings-scan smeert de piek uit, en de absolute helderheid kan intussen gedrift zijn), maar zoek de **nuldoorgang van het verschil A−B** (na gain-correctie):
   - Het verschilsignaal is scherper dan de vlakke som-piek → betere hoekresolutie.
   - Het is ongevoelig voor absolute helderheidsdrift (dimt het licht, dan zakt de som maar blijft de nul op dezelfde hoek).
   - Begrens de fijnregeling tot een venster rond de verwachte positie (bv. ±15°); vind je binnen het venster geen duidelijke nuldoorgang, val dan terug op de stappen-target. Dit voorkomt weglopen bij licht-verandering/ruis.
   Dit corrigeert stepper-slip: de kar draait tot de LDR's daadwerkelijk de uitgelijnde toestand meten, niet tot een geteld stappen-aantal.

**Config:**
- `LDR_PIN_A = GPIO26`, `LDR_PIN_B = GPIO27`
- `WHEEL_BASE_CM = 13,6 cm` — spoorbreedte hart-op-hart, voor graden→cm omrekening. **Stond op 18,5 cm**, terwijl de gemeten spoorbreedte 13,6 cm is; een gecommandeerde 370°-scan draaide daardoor in werkelijkheid **503°**. Moet gelijk blijven aan `TRACK_WIDTH` in `stepper_ramp.py`; empirische correctie (tyre-scrub, backlash) hoort in `ROT_SCALE`.
- **[CONFIG]** `LDR_R_FIXED_OHM = 10 000` — pull-up naar 3V3 (R29/R30). **Geschiedenis: 10 000 → 1000 → weer 10 000.** De stap naar 1 kΩ was voor meer resolutie op de bundelas (1 kΩ geeft ~9,1–16,7 % full-scale i.p.v. ~0,99–1,96 % bij 10 kΩ voor een LDR van 100–200 Ω, ca. 372–683 tegen 41–80 echte 12-bit counts), maar is met de nieuwe, fellere lichtbron weer teruggedraaid. **[TE VERIFIËREN]** of de eerdere zorg — dat de bundelas-Q-daling van ~34 LSB met 10 kΩ nog maar ~4,4 LSB overhoudt en in de ruis verdwijnt — met de fellere bron nog geldt. MicroPython `read_u16()` schaalt deze ruwe ADC-waarde naar 16 bit, dus 12-bit ADC-counts en `read_u16()`-counts mogen niet door elkaar worden gebruikt.
- **[CONFIG]** `LDR_R_MIN_OHM = 20` — ondergrens procentschaal. **Was 60**, waardoor de schaal dichtbij de bron vastklemde op 100 % en de eindfase geen informatie meer had.
- **[CONFIG]** `LDR_R_MAX_OHM = 20 000` — ongewijzigd. Over 20 Ω … 20 kΩ blijft de resolutie 79–1024 werkelijke codes per e-voud, dus het hele werkbereik van 5 m tot 5 cm is bruikbaar.
- **[TE KALIBREREN]** `LDR_GAIN_B = 1,136` — huidige kalibratiefactor voor differentiële meting. **Moet opnieuw gekalibreerd worden**: deze factor compenseerde de tolerantie van een eerder R29/R30-paar, en is sindsdien twee keer van weerstandswaarde gewisseld (zie `LDR_R_FIXED_OHM` hierboven).
- `TARGET_SAMPLES_PER_DEG = 3` — bij 370° ≈ 1110 samples. De scan houdt drie `array`'s van 1110 woorden aan (LDR A, LDR B, stapperstand), samen ~13 KB; ruim binnen RAM.

**Delertopologie:** `R_FIXED` is de **pull-up** naar 3V3, de LDR de pull-down naar GND. Fel licht → lage LDR-weerstand → **lage** ADC-waarde. `_adc_to_res_ohm()` rekent daarop. Controle: schijn licht op LDR A en lees de ruwe ADC; gaat die naar **nul**, dan is de aanname juist.

**100Hz-netrimpel:** een LED-lamp op 230V AC geeft rimpel op de gemeten LDR-spanning met een periode van 10 ms. `measure_now()` en de metingen in `tests/test_ldr_beam.py`/`tests/test_ldr.py` middelen daarom **10 samples, 1 ms uit elkaar** — 10 ms = precies één netperiode, dus de rimpel heft zichzelf op in het gemiddelde. De ISR-sampling tijdens `scan()` (`LDR_SAMPLES_PER_TICK` in `_on_pio_irq`) kan dit **niet** toepassen: die loopt in een hardware-IRQ die niet mag blokkeren, dus die samples volgen elkaar in microseconden op en middelen de netrimpel niet weg. Dat is in de praktijk geen probleem voor de piekbepaling over een hele sweep, maar wel relevant voor een losse, nauwkeurige aflezing — gebruik daarvoor `measure_now()`.

**Publieke functies:**

| Functie | Beschrijving |
|---|---|
| `scan(dir, speed_cm_s, graden, start_graden, go_max, excel, out_csv)` | Voer scan uit. Retourneert dict met resultaten en piekpositie |
| `measure_now(n=10, interval_ms=1)` | Direct LDR-waarde lezen (%, tuple A/B), 1 ms-gemiddeld tegen 100Hz-netrimpel |
| `attach_stepper_reader(fn)` | Koppel stepper.pio_pos1 als positiebron voor de scan |

**`scan()` retourneert:**
```python
{
  'samples': int,        # aantal gemeten samples
  'tick_ms': int,        # gebruikte sample-interval
  'est_time_s': float,   # geschatte scanduur
  'total_deg': float,
  'dist_cm': float,
  'peak_index': int,     # index van lichtmaximum
  'peak_percent': float, # lichtsterkte op maximum (%)
  's1_at_peak': int,     # stapperstand op maximum
  'backtrack': dict,     # terugrijinformatie
  'csv_path': str,       # pad naar CSV (None als niet geschreven)
  'csv_error': str,      # foutmelding (None als ok)
}
```

---

### Rijden naar de lichtbron — positioneren op de bundelas

**Doel: de kar positioneert zich *recht voor* de lichtbron**, op `STOP_DIST_CM = 13,3 cm` (ultrasoon) van het voorwerp — bij de default `OBJECT_W_CM = 6,0 cm`. Rond dit niet af naar 13 cm: bij een **ontwerpdoel** voor de eindnauwkeurigheid van ~0,3 cm eet die afronding de hele foutbegroting op. Dat is meer dan ernaar kijken, en dat verschil bepaalt het hele algoritme.

#### Twee onafhankelijke grootheden, twee signalen

De lichtbron is een **bundelbron** (spleet), geen rondstraler. Daardoor zijn er twee vrijheidsgraden die je apart moet regelen:

| Signaal | Meet | Doel | Regelaar |
|---|---|---|---|
| **A − B** | de *peiling* naar de bron | nul → recht ernaar kijken | `HeadingController`, per slice |
| **Q** (zie onder) | de *positie* t.o.v. de bundelas | maximaal → recht ervóór staan | zijstap tussen de benen |

> **A − B zegt niets over je positie t.o.v. de bundelas.** Je kunt perfect uitgelijnd staan (A = B) en tóch bijna geen licht ontvangen omdat je de bron schuin van de zijkant bekijkt. Nul je alleen de peiling, dan rijdt de kar een achtervolgingskromme: hij kijkt steeds naar de bron maar houdt zijn laterale afwijking. Dat is geen regelprobleem maar een **observeerbaarheidsprobleem** — geen enkele versterking op A − B lost het op, want de informatie zit er niet in.

#### Genormaliseerde helderheid Q

Ontvangen licht is `E = I(φ)/d²`, met `φ = atan(y/d)` de hoek waaronder de bron de kar ziet en `y` de laterale afwijking van de bundelas. Normaliseer de afstand eruit met de ultrasoon:

```
Q = −(1/γ)·ln(R) + 2·ln(d)          ( = ln I(φ) op een constante na )
```

waarbij de lichtsterktes van beide LDR's worden **opgeteld als `R_A^(−1/γ) + R_B^(−1/γ)`** — niet de weerstanden gemiddeld, want die schaal is logaritmisch en niet lineair in licht.

- **Q constant terwijl je nadert** → je zit op de bundelas (φ = 0 op elke afstand).
- **Q daalt terwijl je nadert** → je zit ernaast, want φ groeit. Uit de daling volgt `y`.

Zonder deze normalisatie is dit niet te meten: van 100 naar 12 cm stijgt de 1/d²-term al met een factor ~19 (zie de tabel hieronder), en dat overschaduwt elke laterale gradiënt.

#### Waarom het licht dichtbij juist afneemt

Met de huidige **[AANNAME/VOORLOPIGE SCHATTING]** `w ≈ 33°` (1/e-halfhoek) en een laterale afwijking van 20 cm:

| Afstand | φ | `I(φ)` | 1/d² | ontvangen licht |
|---|---|---|---|---|
| 100 cm | 11,3° | 0,89 | 1,0× | 0,33 |
| 60 cm | 18,4° | 0,73 | 2,6× | 0,70 |
| **40 cm** | 26,6° | 0,52 | 5,2× | **1,00 ← piek** |
| 20 cm | 45,0° | 0,16 | 13× | 0,74 |
| 12 cm | 59,0° | 0,041 | 19× | 0,29 |

De kolom `1/d²` is genormeerd op de rij van 100 cm en rekent met de **schuine** afstand √(d² + y²), niet met `d` alleen; de laatste kolom is `I(φ)` × die factor, genormeerd op de piek.

De bundelafval verslaat 1/d². Vuistregel: **het ontvangen licht piekt rond `d ≈ 2y` en stort daarna in.**

Omgekeerd geldt: **sta je op de bundelas, dan groeit het signaal juist terwijl je nadert.** Het blindheidsprobleem bestaat alleen zolang je scheef staat — dus op de as komen op middellange afstand lost het volledig op.

#### `y` berekenen uit één recht meetbeen

```
Q₁ − Q₂ = (atan(y/d₂)/w)² − (atan(y/d₁)/w)²        →  oplossen naar y (bisectie)
```

Kleine-hoekbenadering voor het gevoel: `y ≈ w·√( ΔQ / (1/d₂² − 1/d₁²) )`.

Eén rechte rit levert dus de **grootte** van de afwijking; alleen het **teken** kost nog één dither (arc links/rechts, kijken welke kant Q verhoogt). Dat is aanzienlijk goedkoper dan iteratief gradiënt-klimmen.

De beenlengte komt uit de **odometer** (nominale stapresolutie 14,9 µm — dat is de resolutie, niet de nauwkeurigheid: microstepping, slip en de kalibratie van `WHEEL_CIRC` zijn een orde grover), niet uit de ultrasoon; die wordt alleen gebruikt voor de absolute startafstand. Daarmee werkt de afstandsfout één keer door in plaats van twee keer — een factor 1,4 winst.

#### Faseopbouw

| Fase | Afstand | Snelheid | Signaal | Actie |
|---|---|---|---|---|
| 1 Zoeken | — | — | A − B, 370°-scan | peiling naar de bron |
| 2 Naderen + meten | 60 → 45 cm | 19,1 cm/s | ΔQ | bereken `y` |
| 3 Teken | 45 cm | 8 cm/s | dither | links of rechts van de as |
| 4 Zijstap | 45 cm | 8 cm/s | odometrie | berekende correctie `y` |
| 5 Herhalen | 45→30, 30→20 cm | 19,1 cm/s | ΔQ | verfijnen, `Q` moet vlak worden |
| 6 Afremmen | 25 cm | → **5 cm/s** | — | stopafstand van 4,4 → 0,5 cm |
| 7 Naar binnen | 20 → 13,3 cm | 5 cm/s | A − B nul, Q bewaken | op de as groeit het signaal |
| 8 Stoppen | 13,3 cm | — | ultrasoon | `mv.finish()` op `approach.brake_target_cm()` |

Fase 2 en 5 kosten geen extra tijd — die afstand moet je toch rijden.

#### Foutbegroting

Twee heel verschillende grootheden:

- **Koers (waar de kar naar kijkt): ruim beter dan ±1°.** De A − B nuldoorgang is scherp, de gyro onderdrukt storingen, en de stapresolutie is 0,0063°.
- **Laterale positie t.o.v. de bundelas: dit is de beperking.**

Detectiedrempel voor `y` per meetbeen (beenlengte uit de odometer, ultrasoon ±3 mm, Q-drift 0,01):

| Been | voorlopig model (w ≈ 33°) | model met gehalveerde spleet (w ≈ 16,5°) |
|---|---|---|
| 60 → 45 cm | 4,55 cm | 2,27 cm |
| 45 → 30 cm | 3,01 cm | 1,50 cm |
| 30 → 20 cm | 2,20 cm | 1,09 cm |
| 20 → 14 cm | 1,72 cm | 0,86 cm |
| **eindafwijking, één doorgang** | **≈ 2 cm** | **≈ 1 cm** |

Deze getallen komen uit `nauwkeurigheid()` in [`tests/test_ldr_beam.py`](tests/test_ldr_beam.py).

De eindwaarde wordt gezet door het laatste been waarop je nog kúnt **bijstellen**, en dat is het been 30 → 20 cm (2,20 cm, afgerond ≈ 2 cm). Het been 20 → 14 cm staat er alleen ter informatie in: daar kan wel gemeten maar niet meer gecorrigeerd worden, want de zijstap moet vóór 20 cm klaar zijn (zie *Stilstaand nameten*). **De beperking is de ultrasoon en de lichtdrift, niet de LDR of de ADC** — ADC-ruis draagt ~0,02 procentpunt bij en is verwaarloosbaar.

Hoe die laterale afwijking zich verhoudt tot wat de grijper kan verdragen staat in *Grijpergeometrie en eindpositionering* hieronder. Kort: **tot een objectbreedte van 4 cm volstaat de huidige opstelling; daarboven is de gehalveerde spleet nodig.**

#### Spleet van de lichtbron

| Effect van halveren | Factor | Beoordeling |
|---|---|---|
| `I(φ)` valt 2× sneller af → Q-signaal ×4 | **y-precisie ×2** | hoofdvoordeel |
| lichtstroom ×0,5 → R van 100 → 162 Ω | | bonus: weg van LDR-verzadiging |
| zoekkegel ×0,5 (halfwaarde 27,5° → 13,7°) | | risico voor fase 1 |

**Zet de spleet verticaal** (hoog en smal): dan versmal je de bundel horizontaal, precies de as waarop je precisie nodig hebt, terwijl hij verticaal breed blijft en hoogteverschillen vergeeft. Een horizontale spleet doet het omgekeerde.

Ter vergelijking: de spleet halveren wint een factor 2, de ultrasoonfout halveren maar √2. De spleet is dus de goedkoopste winst.

#### Randvoorwaarden / afhankelijkheden

- **`γ` (LDR-exponent) en `w` (bundelhalfhoek) moeten gemeten worden** — beide zitten in élke formule hierboven. Zie [`tests/test_ldr_beam.py`](tests/test_ldr_beam.py). De huidige `w ≈ 33°` komt uit één meetpunt met een *aangenomen* `γ = 0,7`; bij `γ = 0,9` is de bundel breder, bij `γ = 0,5` smaller.
- **LDR-gain-kalibratie** (gevoeligheidsverschil A/B); zonder die correctie stuurt de kar scheef.
- **Odometriekalibratie** (`WHEEL_CIRC`, `TRACK_WIDTH`).
- **Hardware/code-koppeling:** R29/R30 zijn (na een tussenstop op 1 kΩ) weer teruggezet naar **10 kΩ**, en `LDR_R_FIXED_OHM` in [`lib/LDR/ldr_scan_isr.py`](lib/LDR/ldr_scan_isr.py) is meegewijzigd naar 10 000. Blijft die op 1000 staan terwijl de hardware op 10 kΩ zit, dan is elke weerstandswaarde een factor 10 fout zonder dat iets faalt — `tests/test_ldr_beam.py` z'n `controleer_config()` vangt dat verschil af. **[TE VERIFIËREN]** de gevoeligheidszorg die destijds tot de stap naar 1 kΩ leidde: de `y`-meting moet een ΔQ van ~0,01 zien, wat met 1 kΩ ongeveer **38 u16-LSB's** was tegen ~4,5 LSB's met 10 kΩ — een factor 8,4. Of de nieuwe, fellere lichtbron dat verschil compenseert (hoger signaalniveau, dus effectief meer LSB's per ΔQ) moet nog op hardware bevestigd worden. De 1 ms-gemiddelde sampling in `measure_now()` (zie boven) onderdrukt alleen de 100Hz-netrimpel, niet deze ADC-quantisatiegrens.
- `LDR_R_MIN_OHM` staat nu op **20 Ω** (was 60 Ω). Voor de bundelasberekening en eindfase heeft werken in `ln R` de voorkeur boven een afgekapte procentschaal; controleer op hardware of 20 Ω voldoende marge tegen verzadiging geeft.
- **Grijsfilter** over de opening als de LDR fysiek verzadigt (100 Ω is erg laag voor CdS). Geen diffusor en geen kleinere opening — die verpesten de richtingsgevoeligheid.
- **Arbitrage met het kompas:** tijdens de nadering is de **LDR leidend** voor de richting; de gyro-Z doet alleen storingsonderdrukking (dat is dus geen dubbele besturing). De **magnetometer** wordt tijdens het rijden níet gebruikt omdat de stappenmotoren het veld verstoren; die is voor de terugweg, waar een absolute koers nodig is.

> **Waarom niet meer segmentgewijs:** de eerdere aanpak (rij kort segment → stop → meet → `rotate()` → herhaal) is vervangen. Bij segmenten van 1–2 cm wordt de topsnelheid nooit gehaald, want de ramp alleen al is 3,28 cm op plus 3,28 cm af. Bovendien kost stop-draai-rij-door ordes meer CPU en wandkloktijd dan bijsturen per slice (~0,1 % CPU), en een stapsgewijze rotatie kan een hobbel of gleuf niet onderdrukken.

---

### Grijpergeometrie en eindpositionering

De kaken sluiten **horizontaal**, maar de vingertoppen bewegen daarbij naar **voren**. Gemeten:

| | Kaakopening | Toppen t.o.v. ultrasoon |
|---|---|---|
| maximaal open | 9 cm | 12 cm |
| bijna dicht | 2 cm | 15 cm |

```
tip_pos_cm(opening) = 12 + (9 − opening) × 3/7        →  0,43 cm vooruit per cm sluiten
```

> Dit is een **rechte door twee meetpunten**. Een vierstangenmechanisme geeft in werkelijkheid een kromme; één extra meting bij ~5 cm opening laat zien hoeveel dat afwijkt.

#### De ultrasoon is alleen bruikbaar met de arm in rust

Tijdens het rijden staan de servo's in rustpositie: de kaken liggen dan **achter** de ultrasoon en vallen buiten de bundel, dus de afstandsmeting is zuiver. Bij een halve openingshoek van 15° is die bundel 6,4 cm breed op 12 cm en **8 cm breed op 15 cm**, en de kaken staan 9 cm open — **zodra de arm uitklapt kijkt de sensor dus naar de eigen vingers.** Vanaf dat moment is er geen afstandsterugkoppeling meer.

#### Drie afgeleide grootheden

Deze geometrie zat eerst in `stepper_ramp.py`. Dat maakte een generieke motordriver afhankelijk van de afmetingen van één grijper en de stopstrategie van één missie; het staat nu in [`lib/gripper/geometry.py`](lib/gripper/geometry.py) (puur rekenwerk, geen imports) en [`lib/gripper/approach.py`](lib/gripper/approach.py) (`finetune()`, `mean_dist_cm()`, `brake_target_cm()`).

| Objectbreedte | Stopafstand `stop_dist_cm()` | Grijpvenster `grip_window_cm()` | Laterale tolerantie `lateral_tolerance_cm()` |
|---|---|---|---|
| 3 cm | 14,6 cm | 12,0 – 14,6 (**2,6 cm**) | ± 3,0 cm |
| 4 cm | 14,1 cm | 12,0 – 14,1 (**2,1 cm**) | ± 2,5 cm |
| 5 cm | 13,7 cm | 12,0 – 13,7 (**1,7 cm**) | ± 2,0 cm |
| 6 cm | 13,3 cm | 12,0 – 13,3 (**1,3 cm**) | ± 1,5 cm |
| 7 cm | 12,9 cm | 12,0 – 12,9 (**0,9 cm**) | ± 1,0 cm |
| 8 cm | 12,4 cm | 12,0 – 12,4 (**0,4 cm**) | ± 0,5 cm |

**Stopafstand:** contra-intuïtief maar juist — een *smaller* voorwerp vraagt een *grotere* stopafstand. Smaller betekent verder sluiten, dus meer vooruitgang van de toppen, dus moet de kar verder terug blijven staan. De default `OBJECT_W_CM = 6.0` geeft `STOP_DIST_CM = 13,3 cm`.

**Grijpvenster:** de vooruitgang van 3 cm is een *gratis* venster bovenop de stopnauwkeurigheid. De ondergrens is conservatief 12 cm; de werkelijke ondergrens wordt bepaald door de **kaakdiepte** (palm t.o.v. toppen), die nog niet is opgemeten.

**Laterale tolerantie:** de kaken vegen tijdens het uitklappen door de ruimte waar het voorwerp staat. Bij een grotere afwijking raakt één kaak het voorwerp en **stoot die het om** — een vervelender faalmodus dan alleen misgrijpen.

> **Voorstel: klap de arm uit bóven het voorwerp en laat hem daarna zakken.** Met twee armscharnieren (servo 1 en 2) kan hetzelfde eindpunt via verschillende paden bereikt worden. Van boven naar beneden komen de kaken om het voorwerp heen in plaats van er horizontaal in; dat elimineert de veegbotsing volledig en kost geen hardware.

#### Laterale nauwkeurigheid versus grijpertolerantie

| Objectbreedte | Grijper-tolerantie | Voorlopig model huidige bundel (≈ ± 2 cm) | Model gehalveerde spleet (≈ ± 1 cm) |
|---|---|---|---|
| 3 cm | ± 3,0 cm | ✓ ruim | ✓ ruim |
| 4 cm | ± 2,5 cm | ✓ | ✓ |
| 5 cm | ± 2,0 cm | ⚠ op de grens | ✓ |
| 6 cm | ± 1,5 cm | ✗ te krap | ✓ |
| 7 cm | ± 1,0 cm | ✗ te krap | ⚠ op de grens |

**Ontwerpverwachting:** met de huidige modelparameters is een gehalveerde spleet nodig voor voorwerpen breder dan 4 cm. Dit wordt pas een definitieve systeemeis nadat `γ` en `w` met `tests/test_ldr_beam.py` zijn gemeten en de laterale fout op de robot is gevalideerd.

#### Stilstaand nameten — het laatste correctiemoment

Omdat de bundel vrij is zolang de arm in rust staat, kan er ná het stoppen maar vóór het uitklappen een verse, gemiddelde meting worden gedaan. Dan vallen de rijsnelheid en de meetlatentie uit de fout:

| | Onzekerheid in de afstand |
|---|---|
| stoppen bij 5 cm/s (committed + latentie) | 0,74 cm |
| **stilstaand nameten + kruipcorrectie** | **ontwerpdoel ≈ 0,3 cm**; hardwarevalidatie nodig |

`approach.finetune(read_cm, object_w_cm)` doet dit (in [`lib/gripper/approach.py`](lib/gripper/approach.py)): gemiddelde over 8 **onafhankelijke** metingen (wachttijd > `INTERVAL_MS` = 50 ms, anders lees je dezelfde gebufferde waarde) en daarna `creep()` naar het doel. Bij 2 cm/s is er praktisch geen ramp nodig, dus de kruipbeweging is meteen exact en zacht. Na een correctie wordt **altijd** opnieuw gemeten, ook na de laatste poging — anders zou het oordeel op de meting van vóór die correctie gebaseerd zijn.

De **laterale** afwijking kan níet worden nagemeten: de `y`-bepaling uit de Q-daling vraagt beweging over twee afstanden. Stilstaand kan alleen worden geverifieerd dat A − B genulled is, en dat is de *peiling*, niet de laterale positie. **De laterale correctie moet dus af zijn op 20–45 cm.**

#### Eindsequentie

| Stap | Actie | Ultrasoon | Terugkoppeling |
|---|---|---|---|
| 1–7 | naderen, bundelas, afremmen naar 5 cm/s | bruikbaar | LDR + gyro + ultrasoon |
| 8 | stoppen rond `STOP_DIST_CM` | bruikbaar | |
| 9 | **`finetune()`** — stilstaand nameten, gemiddeld | bruikbaar | laatste correctiemoment; ontwerpdoel ± 0,3 cm |
| 10 | **`creep()`** naar `stop_dist_cm(breedte)` | bruikbaar | |
| 11 | arm uitklappen **boven** het voorwerp, dan zakken | **blind** | open-loop |
| 12 | grijpen; toppen lopen 12 → 15 cm vooruit | **blind** | stroombegrenzing via PI op ADC2 |

Vanaf stap 11 is alles open-loop; **stap 9–10 is het laatste correctiemoment.** In stap 12 is er nog wél terugkoppeling via de grijperstroomsensor: een greep in de lucht geeft een andere stroomcurve dan een greep om een voorwerp. Dat is het enige "gelukt of niet"-signaal, en het is er al.

---

### `tests/test_ldr_beam.py` — LDR- en bundelkarakterisering

Meetscript voor de constanten waarop de bundelas-positionering rust. Alles vanuit de REPL aan te roepen.

| Functie | Wat | Waar |
|---|---|---|
| `controleer_config()` | of code en gewijzigde hardware bij elkaar passen (draait bij import) | — |
| `gamma()` | LDR-exponent uit 5 afstanden op de as; fit `ln R = 2γ·ln d`, meldt R² | bank |
| `bundel()` | profiel `I(φ)` op een boog met vaste radius, LDR steeds op de bron gericht | bank |
| `nauwkeurigheid()` | haalbare `y`-resolutie per been, met en zonder gehalveerde spleet | geen hardware |
| `meet_y()` | laterale afwijking uit de Q-daling over één rechte rit | op de kar |
| `dither_teken()` | aan welke kant van de bundelas de kar zit | op de kar |

De twee bankmetingen zijn zo opgezet dat ze elk **één factor isoleren**: `gamma()` houdt φ constant (op de as) en varieert alleen de afstand; `bundel()` houdt de afstand én de tunnelhoek constant en varieert alleen φ. `meet_y()` waarschuwt als A − B niet genulled is — dan meet je tunnelvignettering in plaats van de bundel.

---

### `webserver` — microdot-websocket (Pico 2 W)

Webserver op basis van **microdot** (asyncio) met een websocket, zodat het karretje vanuit een standaard browser bediend en uitgelezen kan worden. Is ontworpen om op **core 0** naast de hoofdcontroltaken te draaien; core 1 is gereserveerd voor GY9250 + display. De interactie tussen MicroPython, CYW43/lwIP, `_thread` en de control-loop moet nog onder belasting worden gevalideerd.

**Functionaliteit:**
- **Sensoren uitlezen** (browser, ~5–10 Hz): LDR A/B in %, ultrasoon-afstand in cm (of time-out), kompasrichting in graden, servoposities in %, stepper-snelheid/richting/afgelegde weg.
- **Directe rijbesturing:** vooruit/achteruit/links/rechts + snelheid, met een **noodstop** en een **deadman/heartbeat**: bij een verbroken websocket of uitblijvende heartbeat stopt de kar automatisch.
- **Hoog-niveau commando's:** LDR-scan, rijden-naar-licht, grijpen, terugkeren, kalibratiemodus starten/stoppen.

**Netwerk:** AP-modus (kar als eigen accesspoint) heeft de voorkeur voor mobiel gebruik; station-modus optioneel. SSID/wachtwoord in de centrale `config.json`.

**Aandachtspunten / beperkingen (nog te implementeren):**
- **Async-refactor vereist.** De besturing is nu volledig blokkerend: busy-wait `while sm.active(): pass` in `_wait_stepper_done`, blokkerende `scan()`/ADC-lussen, en `ServoController.servo_rest()` zonder argument, die per servo met `time.sleep_ms(10)` wacht tot de positie bereikt is met een timeout van 5 s — dus tot ~15 s achter elkaar. Die verhongeren alle de asyncio-event-loop. Nodig: coöperatieve taken met `await asyncio.sleep`, of een commandowachtrij + gedeelde state tussen webserver en een control-task.
- **Geheugen:** microdot + asyncio + lwIP + bestaande modules op ~520 KB RAM is haalbaar maar krap — bewaken.
- **Veiligheid:** commandovalidatie en een verplichte deadman-stop (zie boven), zodat een rijdende kar bij connectieverlies niet doorrijdt.

---

## Bekende issues / TODO

- [ ] `lib/LDR/ldr_scan_isr.py` — herzien scan-algoritme implementeren: 370°-scan (geen pre-roll), piek op A≈B-kruispunt i.p.v. som-maximum, kortste weg terug, en closed-loop uitlijnen via null-seek op A−B
- [ ] Gyroscoop/kompas (GY9250) — basis- en fusioncode is aanwezig; integratie, tekenconventie, bias, magnetometerkalibratie en hardwaregedrag met draaiende stappenmotoren nog testen.
- [ ] OLED (SSD1306) — integratie nog niet geïmplementeerd; voorstel staat in `te doen.md`.
- [x] GPIO-tabel gecontroleerd en geverifieerd tegen KiCad netlist V1.2 (zie [hardware/gpio_pinout.md](hardware/gpio_pinout.md))
- [ ] `test_all.py` converteren naar afzonderlijke testfuncties per module; `test_all.py` behouden als snelle controletest.
- [x] Stepper 1/64: `STEPS_REV = 12800` in code gezet. `F_PIO` staat op 15 MHz; de berekende resterende snelheidsafwijking is ~0,43 %.
- [ ] TMC2209 MS-bedrading fysiek verifiëren: `MS1→GND`, `MS2→VCC_IO` (in huidige documentatie +5 V).
- [x] `WHEEL_CIRC` gecorrigeerd naar de gemeten 19,1 cm (was 20,94 → 8,8 % te korte afstanden). `TRACK_WIDTH = 13,6 cm` toegevoegd.
- [ ] `lib/stepper/stepper_ramp.py` op hardware testen: `MOTOR_TURN_SIGN` / `GYRO_Z_SIGN` / `LDR_DIFF_SIGN`, `CYCLES_FIXED` met een logic analyzer, maximale startsnelheid en versnelling meten, regelversterkingen `kp_ldr`/`kp_gyro` afstemmen. Daarna beslissen of `stepper.py` vervalt.
- [ ] **Odometriekalibratie** — afstandsschaal (`WHEEL_CIRC`) en rotatieschaal (`TRACK_WIDTH`) opnemen in de kalibratiesessie. Zonder deze stuurt de kar structureel scheef.
- [ ] Rijden-naar-licht: de segmentgewijze aanpak is **vervangen** door de doorlopende kruisfase met bijsturing per slice in `stepper_ramp.py`, plus positioneren op de **bundelas** via de genormaliseerde helderheid `Q`. Zie de sectie *Rijden naar de lichtbron*.
- [x] `LDR_R_MIN_OHM` naar 20 in `lib/LDR/ldr_scan_isr.py`. Delertopologie gedocumenteerd in de code.
- [x] `LDR_R_FIXED_OHM`: 10 000 → 1000 (voor resolutie op de bundelas) → **weer 10 000**, na het terugzetten van R29/R30 naar 10 kΩ met de nieuwe, fellere lichtbron. `tests/test_ldr_beam.py` (`controleer_config()`) waarschuwt als code en hardware uit elkaar lopen.
- [x] `measure_now()` en de metingen in `tests/test_ldr_beam.py`/`tests/test_ldr.py` middelen nu **10 samples, 1 ms uit elkaar** tegen de 100Hz-netrimpel van de LED-lichtbron (10 ms = één netperiode). Geldt niet voor de ISR-sampling in `scan()`, die niet mag blokkeren.
- [x] `WHEEL_BASE_CM` in `ldr_scan_isr.py` gecorrigeerd van 18,5 naar 13,6 cm — een 370°-scan draaide in werkelijkheid 503°.
- [ ] **`LDR_GAIN_B` opnieuw kalibreren** na de weerstandswissels van R29/R30 (10 kΩ → 1 kΩ → 10 kΩ): die factor compenseerde de tolerantie van een eerder paar en is niet gegarandeerd nog juist.
- [ ] **[TE VERIFIËREN]** of de fellere lichtbron de eerdere resolutiezorg bij 10 kΩ (~4,5 LSB ΔQ op de bundelas, tegen ~38 LSB met 1 kΩ) compenseert — zie *Randvoorwaarden / afhankelijkheden* hierboven.
- [ ] **Delertopologie eenmalig verifiëren op hardware:** schijn licht op LDR A en lees de ruwe ADC. Gaat die naar nul, dan is `_adc_to_res_ohm()` juist; gaat die naar 65535, dan loopt de hele schaal omgekeerd en moet de formule `R_FIXED × (65535 − adc)/adc` worden.
- [ ] **370°-scan opnieuw controleren** met de gecorrigeerde `WHEEL_BASE_CM`. Waren eerdere scans empirisch afgestemd op 18,5, dan wijken piekposities nu af.
- [ ] **`γ` en `w` meten** met `tests/test_ldr_beam.py` (`gamma()` en `bundel()`). Beide constanten zitten in élke `y`-berekening; de huidige `w ≈ 33°` komt uit één meetpunt met een aangenomen `γ = 0,7`.
- [ ] **Spleet lichtbron halveren — voorlopig ontwerpvoorstel voor voorwerpen breder dan 4 cm.** De grijper verdraagt maar ±(9 − breedte)/2 cm laterale afwijking, en de huidige bundel haalt ≈ ±2 cm. Zet de spleet **verticaal** (smal horizontaal). Eerst `bundel()` draaien, dan aanpassen, dan controleren of de 370°-scan de bron nog vindt vanaf de werkelijke startpositie.
- [x] Laterale tolerantie van de grijper vastgesteld: **±(9 − objectbreedte)/2 cm**. Zie *Grijpergeometrie en eindpositionering*.
- [ ] **Kaakdiepte opmeten** (palm t.o.v. vingertoppen). Die zet de werkelijke ondergrens van het grijpvenster; nu conservatief op 12 cm gehouden, wat elk venster ~2 cm te smal maakt.
- [ ] **Derde meetpunt van de grijper** bij ~5 cm opening. `tip_pos_cm()` is nu een rechte door twee punten; een vierstangenmechanisme geeft een kromme.
- [ ] **Arm uitklappen boven het voorwerp en dan laten zakken**, in plaats van horizontaal naar voren vegen. Voorkomt dat een kaak het voorwerp omstoot bij een laterale afwijking. Vraagt een gecoördineerde beweging van servo 1 en 2.
- [ ] Grijsfilter over de LDR-openingen als de cel fysiek verzadigt (100 Ω is erg laag voor CdS). Geen diffusor en geen kleinere opening — die verpesten de richtingsgevoeligheid.
- [ ] **Naamgeving stappenmotoren inconsistent**: `stepper.py`/`stepper_ramp.py` noemen GPIO16/17/18 "motor A", maar [hardware/gpio_pinout.md](hardware/gpio_pinout.md) wijst GPIO16/17/18 toe aan stepper **B** (U2) en GPIO12/13/14 aan stepper A (U1). Functioneel geen probleem, maar code en schema spreken elkaar tegen. Kiezen welke de waarheid is.
- [ ] **BLOCKER vóór vol 6S-accubedrijf — voeding U5 (DSN-MINI-360, MP2307) buiten spec**: gespecificeerd ingangsbereik 4,75–23 V, accu levert 22,2 V nominaal en 25,2 V vol geladen. Er is een 28 V pin-compatibele versie gevonden; die inbouwen. Bij een doorgeslagen high-side schakelaar komt 25 V op de 5 V-rail te staan, wat Pico, servo's, OLED en ultrasoon in één keer meeneemt.
- [ ] **Servo-rail scheiden van de logica-rail** (optioneel): alle servo's hangen op +5 V uit U5 (1,8 A continu / 3 A piek). Drie MG996R kunnen samen 3–4,5 A piek trekken. De grijper heeft al stroombegrenzing via de PI-regelaar op ADC2, en de servo's worden langzaam naar hun eindpositie gestuurd, dus in de praktijk blijft de stroom laag. Bij een onverklaarbare Pico-reset tijdens het grijpen is dit de eerste plek om te kijken.
- [ ] **BLOCKER vóór langdurige motortest:** bulk-elco bij de VM-pin van U1/U2 verifiëren (≥100 µF, korte sporen). Bij 24 V is een spanningspiek uit motorkabel-inductie de klassieke doodsoorzaak van een TMC2209. Nooit de motorstekker loskoppelen terwijl VM aan staat.
- [ ] `webserver` (microdot-websocket, Pico 2 W): sensoruitlezing, directe rijbesturing met deadman, hoog-niveau commando's; vereist async-refactor van de blokkerende besturing.
- [ ] Exacte MicroPython-build en CPython-versie vastleggen in deze specificatie.

---

## Afhankelijkheden

MicroPython voor **Raspberry Pi Pico 2 W (RP2350 + CYW43439)**. **Exacte firmwareversie/build nog vastleggen** voor reproduceerbaarheid. Externe libraries: `mpu9250`, `mpu6500`, `ak8963` (Tuupola, via awesome-micropython), `ssd1306` (SSD1306 OLED driver), `microdot` (asyncio-webserver met websocket-ondersteuning).

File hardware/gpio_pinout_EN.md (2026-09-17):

# GPIO Pinout — DIY Robot Car (Revision V1.2, RP2350)

> **Status: VERIFIED** — GPIO table has been checked against KiCad netlist V1.2 (export 2026-06-09).

## GPIO table

| GPIO | Direction | Function | Component / Net | Note |
|---|---|---|---|---|
| GPIO0 | OUT (SDA) | I2C0 SDA | U6 SSD1306 OLED — net `/SDA0` | Used as I2C0 SDA (GP0) |
| GPIO1 | OUT (SCL) | I2C0 SCL | U6 SSD1306 OLED — net `/SCL0` | Used as I2C0 SCL (GP1) |
| GPIO2 | OUT (PWM) | Servo 1 PWM | J1 (JST-XH 3) — MG996R lower hinge arm | |
| GPIO3 | OUT (PWM) | Servo 2 PWM | J2 (JST-XH 3) — MG996R upper hinge arm | |
| GPIO4 | OUT (PWM) | Servo 3 PWM | J3 (JST-XH 3) — third servo | Previously listed as NC; netlist confirms connection |
| GPIO5 | IN | PWM tick for servo ISR | Not connected on PCB (no-connect marker) | Connect externally to GPIO2 with wire |
| GPIO6 | OUT | WS2812B data | D2 WS2812B — net `Net-(D2-DIN)` | |
| GPIO7 | — | NC | — | |
| GPIO8 | — | NC | — | |
| GPIO9 | — | NC | — | |
| GPIO10 | BIDI (SDA) | I2C1 SDA | J7 pin 4 — GY9250 gyroscope/compass | *Not yet implemented* |
| GPIO11 | BIDI (SCL) | I2C1 SCL | J7 pin 3 — GY9250 gyroscope/compass | *Not yet implemented* |
| GPIO12 | OUT | DIR stepper A | U1 TMC2209 pin DIR — net `Net-(U1-DIR)` | |
| GPIO13 | OUT | STEP stepper A | U1 TMC2209 pin STEP — net `Net-(U1-STEP)` | |
| GPIO14 | OUT | ENABLE stepper A | U1 TMC2209 pin ~ENABLE — net `Net-(U1-~{ENABLE})` | Low = enabled |
| GPIO15 | OUT (PWM) | Laser PWM | Q1 BS170 MOSFET gate — net `Net-(Q1-G)` | Via R10 (100 Ω) and Q1 BS170 to J6 (laser) |
| GPIO16 | OUT | DIR stepper B | U2 TMC2209 pin DIR — net `Net-(U2-DIR)` | |
| GPIO17 | OUT | STEP stepper B | U2 TMC2209 pin STEP — net `Net-(U2-STEP)` | |
| GPIO18 | OUT | ENABLE stepper B | U2 TMC2209 pin ~ENABLE — net `Net-(U2-~{ENABLE})` | Low = enabled |
| GPIO19 | IN | Echo ultrasonic sensor | J13 pin 2 — net `/Echo` | |
| GPIO20 | OUT | Trigger ultrasonic sensor | J13 pin 3 — net `/Trig` | |
| GPIO21 | — | NC | — | |
| GPIO22 | OUT (PWM) | Servo 4 PWM (gripper) | J10 pin 1 — net `Net-(J10-Pin_1)` | With current limitation via PI; current sensor on J10 pin 3 |
| GPIO26 | IN (ADC0) | LDR A | J8 (JST-XH 2) — net `Net-(J8-Pin_1)` | Pull-up R29 (10 kΩ) to 3V3; filter C13 |
| GPIO27 | IN (ADC1) | LDR B | J9 (JST-XH 2) — net `Net-(J9-Pin_1)` | Pull-up R30 (10 kΩ) to 3v3; filter C15 |
| GPIO28 | IN (ADC2) | Current sensor gripper | R22 (1 kΩ) ← U3B output — net `/I_Servo` | Filter C10; see circuit below |

## Stepper drivers

The circuit uses **TMC2209** drivers (U1 and U2). The KiCad footprint is labeled as A4988 but the installed component is TMC2209.

### Connector overview

| Connector | GPIO side | Engine side | Engine |
|---|---|---|---|
| J4 (JST-XH 4) | U1 TMC2209 | 1A / 1B / 2A / 2B | Stepper A |
| J5 (JST-XH 4) | U2 TMC2209 | 1A / 1B / 2A / 2B | Stepper B |

### Microstepping setting (TMC2209)

MS pins are hardwired (TMC2209). The original 10 kΩ pull-ups have been removed; MS1 and MS2 are now fixed for **1/64 microstepping**:

| Pin | Connection | Condition |
|-----|---|---|
| MS1 | → GND | Low |
| MS2 | → +5V | High |

TMC2209 truth table (MS2, MS1): GND/GND → 1/8 · GND/VIO → 1/32 · **VIO/GND → 1/64** · VIO/VIO → 1/16.

With MS2=H (VIO), MS1=L (GND) → **1/64 microstepping**

→ 200 steps/revolution × 64 = **12800 steps per revolution**

Same goes for U2.

> **History:** Previously documented as 1/8 (1600 steps/rev) based on A4988 footprint logic. The actual driver is a TMC2209 and the MS wiring has been adjusted to 1/64 to allow for a smoother implementation of the stepper ramp.

## Gripper servo circuit (GPIO28)

```
Servo 4 GND ── R31 (0,1 Ω shunt) ── GND
                        │
                  net /Isense
                  │           │
               R3 (20 kΩ)  R13 (2,4 kΩ)
                  │           │
              U3A (+)      U3B (+) ─── C9
              U3A (-) ← R2 (3,9 kΩ) ← GNDA
              U3A (-) ← R4 (47 kΩ) ← U3A output
              U3A output → R9 (16 kΩ) → net C8
              U3B (-) = U3B output (voltage follower trap)
              U3B output → R22 (1 kΩ) → GPIO28 (ADC2)
```

- IC: U3 OPA2705 (DIP-8 socket) — dual op amp
- Filter C10 (1 nF) on GPIO28
- Net `/I_Servo` connects R22 pin 1 to GPIO28

## Servo connectors (JST-XH 3-pin)

Pin order: **pin 1 = signal, pin 2 = +5V, pin 3 = GND**

| Connector | GPIO | Servo |
|---|---|---|
| J1 | GPIO2 | Servo 1 — lower hinge arm |
| J2 | GPIO3 | Servo 2 — upper hinge arm |
| J3 | GPIO4 | Servo 3 |
| J10 | GPIO22 | Servo 4 — gripper (pin 3 = /Isense) |

## Ultrasonic sensor connector

J13 (JST-XH 4): **pin 1 = GND, pin 2 = Echo (GPIO19), pin 3 = Trig (GPIO20), pin 4 = +5V**

## Laser circuit

GPIO15 → R10 (100 Ω) → Q1 BS170 gate. Drain via J6 to laser. Source to GND.

## PWM tick connection

GPIO5 has **no PCB connection** (no-connect in schematic).
Connect externally: a wire from GPIO2 (servo1 PWM output) to GPIO5 (input).
The falling edge of the 50 Hz servo PWM signal triggers the servo update ISR.

## Verified items (netlist V1.2)

- [x] GPIO0 SDA / GPIO1 SCL → OLED U6 ✓
- [x] GPIO2 servo 1 (J1) ✓
- [x] GPIO3 servo 2 (J2) ✓
- [x] GPIO4 servo 3 (J3) — **new, was NC**
- [x] GPIO5 NC on PCB (external to GPIO2) ✓
- [x] GPIO6 WS2812B (D2) ✓
- [x] GPIO10–11 gyroscope J7 ✓
- [x] GPIO12–14 stepper A (U1 TMC2209) ✓
- [x] GPIO15 laser MOSFET Q1 BS170 ✓
- [x] GPIO16–18 stepper B (U2 TMC2209) ✓
- [x] GPIO19–20 ultrasonic sensor J13 ✓
- [x] GPIO22 servo 4 gripper (J10) ✓
- [x] GPIO26–27 LDR (J8, J9) ✓
- [x] GPIO28 current sensor via U3 OPA2705 ✓
- [x] Stepper driver type: **TMC2209** (KiCad footprint labeled A4988; installed component is TMC2209) ✓
- [x] Microstepping: **1/64** (TMC2209, MS2=H/VIO, MS1=L/GND) → 12800 steps/rev — MS wiring to be physically verified

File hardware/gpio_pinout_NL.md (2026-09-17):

# GPIO Pinout — DIY Robot Car (Revisie V1.2, RP2350)

> **Status: GEVERIFIEERD** — GPIO-tabel is gecontroleerd tegen KiCad netlist V1.2 (export 2026-06-09).

## GPIO-tabel

| GPIO | Richting | Functie | Component / Net | Opmerking |
|---|---|---|---|---|
| GPIO0 | OUT (SDA) | I2C0 SDA | U6 SSD1306 OLED — net `/SDA0` | Gebruikt als I2C0 SDA (GP0) |
| GPIO1 | OUT (SCL) | I2C0 SCL | U6 SSD1306 OLED — net `/SCL0` | Gebruikt als I2C0 SCL (GP1) |
| GPIO2 | OUT (PWM) | Servo 1 PWM | J1 (JST-XH 3) — MG996R onderste scharnier arm | |
| GPIO3 | OUT (PWM) | Servo 2 PWM | J2 (JST-XH 3) — MG996R bovenste scharnier arm | |
| GPIO4 | OUT (PWM) | Servo 3 PWM | J3 (JST-XH 3) — derde servo | Eerder als NC genoteerd; netlist bevestigt verbinding |
| GPIO5 | IN | PWM-tick voor servo ISR | Niet verbonden op PCB (no-connect marker) | Extern aansluiten op GPIO2 met draad |
| GPIO6 | OUT | WS2812B data | D2 WS2812B — net `Net-(D2-DIN)` | |
| GPIO7 | — | NC | — | |
| GPIO8 | — | NC | — | |
| GPIO9 | — | NC | — | |
| GPIO10 | BIDI (SDA) | I2C1 SDA | J7 pin 4 — GY9250 gyroscoop/kompas | *Nog niet geïmplementeerd* |
| GPIO11 | BIDI (SCL) | I2C1 SCL | J7 pin 3 — GY9250 gyroscoop/kompas | *Nog niet geïmplementeerd* |
| GPIO12 | OUT | DIR stepper A | U1 TMC2209 pin DIR — net `Net-(U1-DIR)` | |
| GPIO13 | OUT | STEP stepper A | U1 TMC2209 pin STEP — net `Net-(U1-STEP)` | |
| GPIO14 | OUT | ENABLE stepper A | U1 TMC2209 pin ~ENABLE — net `Net-(U1-~{ENABLE})` | Low = ingeschakeld |
| GPIO15 | OUT (PWM) | Laser PWM | Q1 BS170 MOSFET gate — net `Net-(Q1-G)` | Via R10 (100 Ω) en Q1 BS170 naar J6 (laser) |
| GPIO16 | OUT | DIR stepper B | U2 TMC2209 pin DIR — net `Net-(U2-DIR)` | |
| GPIO17 | OUT | STEP stepper B | U2 TMC2209 pin STEP — net `Net-(U2-STEP)` | |
| GPIO18 | OUT | ENABLE stepper B | U2 TMC2209 pin ~ENABLE — net `Net-(U2-~{ENABLE})` | Low = ingeschakeld |
| GPIO19 | IN | Echo ultrasoonsensor | J13 pin 2 — net `/Echo` | |
| GPIO20 | OUT | Trigger ultrasoonsensor | J13 pin 3 — net `/Trig` | |
| GPIO21 | — | NC | — | |
| GPIO22 | OUT (PWM) | Servo 4 PWM (grijper) | J10 pin 1 — net `Net-(J10-Pin_1)` | Met stroombeperking via PI; stroomsensor op J10 pin 3 |
| GPIO26 | IN (ADC0) | LDR A | J8 (JST-XH 2) — net `Net-(J8-Pin_1)` | Pull-up R29 (10 kΩ) naar 3V3; filter C13 |
| GPIO27 | IN (ADC1) | LDR B | J9 (JST-XH 2) — net `Net-(J9-Pin_1)` | Pull-up R30 (10 kΩ) naar 3v3; filter C15 |
| GPIO28 | IN (ADC2) | Stroomsensor grijper | R22 (1 kΩ) ← U3B output — net `/I_Servo` | Filter C10; zie stroomkring hieronder |

## Stepper drivers

De schakeling gebruikt **TMC2209** drivers (U1 en U2). De KiCad footprint is gelabeld als A4988 maar de geplaatste component is TMC2209.

### Connector-overzicht

| Connector | GPIO-kant | Motor-kant | Motor |
|---|---|---|---|
| J4 (JST-XH 4) | U1 TMC2209 | 1A / 1B / 2A / 2B | Stepper A |
| J5 (JST-XH 4) | U2 TMC2209 | 1A / 1B / 2A / 2B | Stepper B |

### Microstepping instelling (TMC2209)

MS-pinnen zijn hardwired (TMC2209). De oorspronkelijke 10 kΩ pull-ups zijn verwijderd; MS1 en MS2 worden nu vast gezet voor **1/64 microstepping**:

| Pin | Verbinding | Toestand |
|-----|---|---|
| MS1 | → GND | Laag |
| MS2 | → +5V | Hoog |

TMC2209 waarheidstabel (MS2, MS1): GND/GND → 1/8 · GND/VIO → 1/32 · **VIO/GND → 1/64** · VIO/VIO → 1/16.

Met MS2=H (VIO), MS1=L (GND) → **1/64 microstepping**

→ 200 stappen/omw × 64 = **12800 stappen per omwenteling**

Zelfde geldt voor U2.

> **Historie:** eerder gedocumenteerd als 1/8 (1600 stappen/omw) op basis van de A4988-footprintlogica. De feitelijke driver is een TMC2209 en de MS-bedrading is aangepast naar 1/64 om de stepper-ramp gladder te kunnen implementeren.

## Stroomkring grijper-servo (GPIO28)

```
Servo 4 GND ── R31 (0,1 Ω shunt) ── GND
                        │
                  net /Isense
                  │           │
               R3 (20 kΩ)  R13 (2,4 kΩ)
                  │           │
              U3A (+)      U3B (+) ─── C9
              U3A (-) ← R2 (3,9 kΩ) ← GNDA
              U3A (-) ← R4 (47 kΩ) ← U3A output
              U3A output → R9 (16 kΩ) → net C8
              U3B (-) = U3B output (voltage follower trap)
              U3B output → R22 (1 kΩ) → GPIO28 (ADC2)
```

- IC: U3 OPA2705 (DIP-8 socket) — dual opamp
- Filter C10 (1 nF) op GPIO28
- Net `/I_Servo` verbindt R22 pin 1 met GPIO28

## Servo connectors (JST-XH 3-pin)

Pinvolgorde: **pin 1 = signaal, pin 2 = +5V, pin 3 = GND**

| Connector | GPIO | Servo |
|---|---|---|
| J1 | GPIO2 | Servo 1 — onderste scharnier arm |
| J2 | GPIO3 | Servo 2 — bovenste scharnier arm |
| J3 | GPIO4 | Servo 3 |
| J10 | GPIO22 | Servo 4 — grijper (pin 3 = /Isense) |

## Ultrasoonsensor connector

J13 (JST-XH 4): **pin 1 = GND, pin 2 = Echo (GPIO19), pin 3 = Trig (GPIO20), pin 4 = +5V**

## Laser circuit

GPIO15 → R10 (100 Ω) → Q1 BS170 gate. Drain via J6 naar laser. Source naar GND.

## PWM-tick verbinding

GPIO5 heeft **geen PCB-verbinding** (no-connect in schematic).
Sluit extern aan: een draad van GPIO2 (servo1 PWM output) naar GPIO5 (input).
De falling edge van het 50 Hz servo-PWM signaal triggert de servo-update ISR.

## Geverifieerde items (netlist V1.2)

- [x] GPIO0 SDA / GPIO1 SCL → OLED U6 ✓
- [x] GPIO2 servo 1 (J1) ✓
- [x] GPIO3 servo 2 (J2) ✓
- [x] GPIO4 servo 3 (J3) — **nieuw, was NC**
- [x] GPIO5 NC op PCB (extern naar GPIO2) ✓
- [x] GPIO6 WS2812B (D2) ✓
- [x] GPIO10–11 gyroscoop J7 ✓
- [x] GPIO12–14 stepper A (U1 TMC2209) ✓
- [x] GPIO15 laser MOSFET Q1 BS170 ✓
- [x] GPIO16–18 stepper B (U2 TMC2209) ✓
- [x] GPIO19–20 ultrasoonsensor J13 ✓
- [x] GPIO22 servo 4 grijper (J10) ✓
- [x] GPIO26–27 LDR (J8, J9) ✓
- [x] GPIO28 stroomsensor via U3 OPA2705 ✓
- [x] Stepper driver type: **TMC2209** (KiCad footprint gelabeld A4988; geplaatste component is TMC2209) ✓
- [x] Microstepping: **1/64** (TMC2209, MS2=H/VIO, MS1=L/GND) → 12800 stappen/omw — MS-bedrading fysiek te verifiëren

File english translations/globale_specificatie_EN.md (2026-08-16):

# DIY Robot Car — MicroPython on RP2350 (Pico 2 W)

## System description

An autonomously moving robot cart that searches for a light source, drives towards it, picks up an object with a gripping arm and then returns to its starting position.

### Status of values 

In this document, design values are indicated where necessary as follows:

- **[MEASURED]** — measured directly on the current robot/hardware.
- **[CALCULATED]** — derived from measured values, datasheet values or software constants.
- **[ASSUMPTION]** — used in the design model, but not yet sufficiently measured.
- **[TO BE VERIFIED]** — hardware or software behavior that has yet to be explicitly tested.

High numerical resolution is not automatically the same quantity as physical accuracy. Wheel slip, tire deformation, sensor bias, mechanical play and calibration remain separate sources of error.

### Work order

1. **LDR scan** — Turn one full turn + overlap (**370°**) in one direction and measure light intensity with two paired LDRs. A complete revolution always contains the maximum; the 10° overlap prevents a peak around 0°/360° from falling on the edge. So no pre-roll (rolling back before the scan) is needed anymore.
2. **Align** — Turn to the found direction via the **shortest path** (turn forward or back, depending on which angle is smaller). The last degrees are always approached in the same direction so that the backlash/backlash remains constant. The end position is adjusted in a closed-loop manner via the LDRs (see below). This corrects angle/alignment errors due to missed steps or mechanical deviation; this is not a detection or correction of general linear wheel slip.
3. **Driving with LDR correction** — Drive to the light source and continuously correct for course deviation along the way: as long as there is a difference between the two LDR values (after gain correction), the cart will adjust towards the brightest side until A ≈ B. Stop at the set distance via the ultrasonic sensor (runs independently in the background, SM4).
4. **Grab** — Control two hinge servos so that the arm reaches the object.
5. **Close gripper** — Servo 4 with current limitation (PI limiter) so that the servo is not overloaded.
6. **Return** — Turn around and return to the starting position via stored cycling odometry/route information; place object. Its accuracy is limited by cumulative odometry error and wheel slip.
7. **GY9250 support** — gyro and magnetometer can support orientation/heading. They do not provide an absolute X/Y position. Software is present, but integration and hardware calibration have not yet been validated.

---

## Hardware

| Component | Quantity | Type | Connection |
|---|---|---|---|
| Stepper motor | 2 | — | Driver: TMC2209 |
| Servo motor (arm) | 2 | MG996R | GPIO2, GPIO3 |
| Servo motor (gripper) | 1 | MG996R | GPIO22 — with current sensor |
| Servo motor (optional/spare) | 1 | MG996R | GPIO4 — wired to PCB, not yet connected/deployed |
| Ultrasonic sensor | 1 | RCWL-1601 | GPIO19 (Echo), GPIO20 (Trig) |
| LDR | 2 | 1 kΩ voltage divider (pull-up to 3V3) | GPIO26, GPIO27 |
| Laser (cross hair) | 1 | — | GPIO15 via MOSFET |
| OLED | 1 | SSD1306 | I2C0: SDA=GPIO0, SCL=GPIO1 |
| Gyroscope/compass | 1 | GY9250 | I2C1: SDA=GPIO10, SCL=GPIO11 — *software provided (`lib/GY9250`, fusion, stepper link); integration and hardware calibration not yet validated* |
| Current sensor gripper | — | 0.1 Ω shunt + op amp (gain 14×) | ADC2 = GPIO28 |
| LED | 1 | WS2812B | GPIO6 |
| WiFi/Bluetooth | 1 | Infineon CYW43439 (onboard Pico 2 W) | internal board connection |

The robot controller is a **Raspberry Pi Pico 2 W** with a **RP2350** microcontroller and an onboard **Infineon CYW43439** wireless controller. In MicroPython this is controlled via the CYW43 driver. The web server/web socket control uses WiFi; the planned software architecture keeps networking and main control tasks on core 0 and reserves core 1 for GY9250/display tasks. This core distribution still needs to be validated as a whole on hardware.

See [hardware/gpio_pinout.md](hardware/gpio_pinout_EN.md) for the full GPIO table and verification status.

### Development environment

| Part | Configuration |
|---|---|
| Robot board | Raspberry Pi Pico 2W |
| Microcontroller | RP2350 |
| Robot firmware | MicroPython for Pico 2 W — **exact version/build yet to be determined** |
| Development PC | Fedora Linux 44 |
| Desktop | KDE Plasma |
| PC Tests | CPython; pure-Python tests from `tests/` |
| Hardware Validation | logic analyzer for PIO/STEP timing; multimeter/measuring setup for power supply and sensor calibration |

> **[TO BE VERIFIED] Reproducibility:** Before final hardware testing, record the exact MicroPython version/build and the CPython version used. The software uses RP2350 specific features such as PIO2 and `rp2.DMA()`.

---

## Software modules

### PIO State Machine assignment

| SM | Module | Function |
|---|---|---|
| SM0 | stepper/stepper.py *or* stepper_ramp.py | Step generator motor A |
| SM1 | stepper/stepper.py *or* stepper_ramp.py | Step generator motor B |
| SM2 | stepper/stepper.py *or* stepper_ramp.py | Pedometer motor A |
| SM3 | stepper/stepper.py *or* stepper_ramp.py | Pedometer motor B |
| SM4 | ultrasonic/ultrasonic.py | Ultrasonic sensor trigger + echo measurement |
| SM8 | LDR/ldr_scan_isr.py | Variable clock for LDR sample timing (PIO2 SM0) |

PIO0 is now full (4 of 4 SMs). `stepper.py` and `stepper_ramp.py` are **alternatives** — they claim the same SMs and the same GPIOs, so always import only one.

### DMA channel assignment

| Channel | Module | Function |
|---|---|---|
| 2 pieces (dynamically claimed via `rp2.DMA()`) | stepper/stepper_ramp.py | Rampatabel → TX-FIFO of SM0 / SM1 |

The RP2350 has 16 DMA channels; `treq_sel = (pio_num << 3) + sm_num` (also correct on RP2350, `DREQ_PIO2_TX0 = 16`).

---

### `lib/stepper/stepper.py`

Dual stepper motor controller based on PIO. Both motors run independently via their own SM and counter SM.

**Constants:**
- **[MEASURED]** `WHEEL_CIRC = 19,1 cm` — wheel circumference. Was 20.94 cm; that value gave **8.8% too short distances** (50 cm commanded → 45.6 cm driven). The loaded rolling circumference of a rubber wheel is slightly smaller than the free circumference, so calibrate this value (see *Odometry calibration* below).
- **[MEASURED]** `TRACK_WIDTH = 13,6 cm` — geometric track gauge center-to-center. Necessary for every rotation and rate calculation.
- `STEPS_REV = 12800` — steps per revolution (**1/64 microstepping**, TMC2209: 200 full steps × 64). MS pins hardwired: **MS1 → GND, MS2 → VCC_IO** *(denoted as +5 V in current documentation; physically verify)* (see [hardware/gpio_pinout.md](hardware/gpio_pinout_EN.md)).
- **[CALCULATED]** `CM_PER_STEP ≈ 14,9 µm/stap`
- **[CALCULATED]** `STEPS_PER_DEG ≈ 159` — steps difference between the wheels per degree change in heading. So resolution is **0.0063°**.
- **[CALCULATED/CONFIG]** `F_PIO = 15 MHz` — 150 MHz sysclk / 10, so an **integer clock divider** (no jitter from the fractional divider). `speed_to_delay()` gives the value **576** at the top speed of 12800 steps/s. The delay loop of this PIO is two instructions (`nop().side(0)` + `jmp(y_dec)`), so each unit is 2 cycles and the **speed resolution is 0.17%**. The STEP pulse remains for 11 cycles = **733 ns**, well above the TMC2209 minimum of ~100 ns.
> The often mentioned 1167 cycles and 0.085% do not belong here but with `_delay_for()` in `stepper_ramp.py`, where the delay loop is one cycle per unit. Don't confuse the two.

> **`OVERHEAD` in `speed_to_delay()`:** remains at the hardware-measured 9. The PIO loop actually costs 13 cycles of fixed overhead while the formula assumes 18; at 15 MHz, that **systematic** deviation at top speed automatically drops from ~2.3% to ~0.43%, so re-measurement is no longer necessary. (Previously this was ~11%; that was estimated too high.) In addition, the cutoff of `int()` is added, a maximum of 2 cycles ≈ 0.17%.

**Public functions:**

| Function | Description |
|---|---|
| `mov(dir, speed, dist)` | Both engines simultaneously. `dir='f'/'b'`, speed in cm/s, dist in cm |
| `s1(dir, speed, dist)` | Engine A | only
| `s2(dir, speed, dist)` | Engine B | only
| `rotate(dir, speed, dist)` | Turn on the axle. `dir='l'/'r'`, dist in cm (wheel arc length) |
| `stop()` | Stop both SMs immediately |
| `enable()` / `disable()` | Turn driver enable on/off |
| `status()` | Print position and status of both engines |
| `distance()` | Print and return PIO step distance (cm) |
| `reset_PIO_distance()` | Reset hardware counters to zero |
| `pio_pos1()` / `pio_pos2()` | Read number of steps motor A/B from PIO |

**Step Generator (PIO) Operation:**
- `pull(noblock)` takes a delay value from the TX FIFO (or reuses the previous one).
- The delay determines the step frequency → speed.
- The counter SM counts STEP edges and generates an IRQ when the target is reached.
- IRQ handler stops the associated engine SM and updates the software position.

**Limitation:** there is no disaster. The speed is commanded in one go, so from a standstill the rotor must jump to the final speed within one microstep (78 µs). That is infinite acceleration: the rotor cannot follow the field, loses synchronism and the motor remains humming. This is a **synchronism error, not a torque error** — see the torque budget below. `stepper_ramp.py` solves this.

---

### `lib/stepper/stepper_ramp.py`

Dual stepper motor controller **with ramp** (PIO + DMA) and continuous course correction. Replaces `stepper.py`.

It is an **API largely compatible successor, not a drop-in replacement.** Named `mov`, `s1`, `s2`, `rotate`, `stop`, `enable`, `disable`, `status`, `distance`, `pio_pos1/2` and `reset_PIO_distance` still exist with the same meaning, but during migration these are the breakpoints:

| Difference | Consequence |
|---|---|
| No more global `sm0`..`sm3` | code that comes directly there breaks |
| The generator SMs remain **permanently active** and reside on an empty FIFO | waiting for `sm0.active()` no longer works; use `busy()` |
| `distance()` prints nothing and returns **one signed center distance** instead of two motor distances | callers that extract two values break |
| The motion functions return `True`/`False` instead of implicitly `None` | only relevant if the return value was used |
| Other stop and completion semantics | `halt()` / `brake()` / `emergency_stop()` are now three different things |
| `reset_PIO_distance()` refuses during a movement | first call `halt()` or `brake()` |
| Invalid input returns `ValueError` instead of silently calculating | a negative `dist` was previously made quietly positive |

#### Design basis

| Greatness | Value |
|---|---|
| Mass cart | **[MEASURED]** 1636 g |
| Wheel circumference / radius | **[MEASURED/CALCULATED]** 19.1 cm / 3.04 cm |
| Track width (center-to-center) | **[MEASURED]** 13.6 cm geometric |
| Engine | 17HS8401 — NEMA 17, 1.7 A, 52 N·cm, 1.8 Ω, 3.2 mH, rotor 68 g·cm² |
| Driver | TMC2209, standalone, **stealthChop**, 1/64 microstepping |
| VREF / motor current | **[CALCULATED, TO BE VERIFIED]** 1.0 V → approx. **0.71 A RMS** according to current driver assumptions; check sense resistor/driver version |
| Motor voltage | 24 V (6S Li-ion, 25.2 V full → ~18 V empty) |
| Achieve speed | **[DESIGN VALUE, TO BE VERIFIED]** start 0.1 rev/s = 1.91 cm/s · max 1.0 rev/s = 19.1 cm/s |

**Linking budget [CALCULATED]** — this budget supports the choice for a disaster and shows a large linking margin on paper; the actual margin should be confirmed with the current motor current and load on hardware:

| Mail | Torque per wheel |
|---|---|
| Acceleration of 1636 g at 55 cm/s² | 1.37 N·cm |
| Rotor inertia (68 g cm²) | 0.013 N·cm |
| Rolling resistance (well estimated) | ~1.2 N·cm |
| **Total required** | **~2.6 N·cm** |
| **Available at VREF 1 V** | **~22 N·cm** → factor 8 margin |

The item "accelerate" is `m·a/2 × r` = 1.636 kg × 0.55 m/s² ÷ 2 wheels × 0.0304 m; the wheels' own inertia is not yet present, but that is not interesting at this margin.

At 22 N·cm and wheel radius 3.04 cm, the pulling force is 7.2 N per wheel (14.5 N total) against a weight of 16.1 N: the **wheels slip rather than the engine lacking torque**. Therefore, VREF = 1.0 V is an appropriate design setting for the time being (1.8 W dissipation instead of 10.4 W at full power). stealthChop is sufficient: the practical ceiling is ~300 rpm and the cart rotates at 60 rpm. The SPREAD pin does not need to be connected.

#### FIFO word format

Each 32-bit word in the TX-FIFO encodes a whole **segment** instead of one step:

| Bits | Contents |
|---|---|
| 15..0 | number of steps in this segment − 1 (max 65536) |
| 31..16 | delay per step in PIO cycles (max 65535) |

As a result, a ramp of 2200 steps only costs 256 words = **1 KB**. One 32-bit word per step would cost 2200 × 4 = **8800 bytes ≈ 8.6 KiB per ramp**. Four separate tables (up/down for two engines) would together require approximately **34.4 KiB**, excluding Python object overhead. Segment coding greatly reduces this. A cross phase up to **97.8 cm** fits in a single word.

The PIO loop is 7 instructions; fixed overhead **5 cycles per step** (0.43% at top speed).

#### Phases of a Movement

| Phase | Source | CPU costs |
|---|---|---|
| Disaster on | DMA table, 256 words | **0** — ~2 ms segments are too fast for MicroPython; DMA is required here and immune to GC breaks |
| Cross phase **without** adjustment | same DMA transfer, 1 word | **0** |
| Cross phase **with** adjustment | CPU pushes 1 word per 20 ms per engine | ~0.1% (≈100 `put()`/s) |
| Disaster | DMA table, 256 words | **0** |

A complete 50 cm move without adjustment is **513 words = 2052 bytes in one DMA transfer** — the same zero-overhead behavior as the old concept, with ramp. There is **no interrupt**: `stepper_ramp.py` does not configure a DMA or PIO IRQ anywhere. During execution, the CPU does nothing, and completion is polled with `busy()`. (The old `stepper.py` above did have `sm2.irq`/`sm3.irq`.)

**With an empty FIFO, `pull(block)` stalls with STEP low.** Consequences:
- the motor holds its position, no step is lost;
- CPU latency (also a GC pause of tens of ms) affects **step timing** — the PIO generates with hardware precision. Late CPU means the correction comes one slice later, not a timing error;
- if the FIFO is really empty, the result is a short pause, not a glitch. This is neatly degrading failure behavior, unlike a CPU timed pulse generator.

With 3 slices ahead in the FIFO, the runway is **60 ms** and the control latency is also ≤60 ms.

**DMA and CPU should never write to the same FIFO simultaneously** — the order would be mixed up and the two engines could have different segment orders, making both the ramp and the course unreliable. Therefore:

- during ramp-up the CPU does not push anything; `Move.service()` waits until `dma.active()` of **both** engines is `False`. The DMA has then stopped *writing* while the FIFO still contains data — just the head start the CPU needs.
- the ramp-off DMA will not be started until the CPU has stopped pushing.

> Waiting until the ramp steps have also been *executed* would be wrong: then the FIFO will run empty and the engine will pause between ramp and cruise phase.

**Bridge segment.** When the ramp-up DMA has finished writing, there are a maximum of 4 words left in the FIFO. At the end of the ramp we are at top speed, so those 4 words together are only ~3 ms — with `service()` every 10 ms the FIFO would still empty. Therefore, the ramp-up table ends with one **bridge segment** at a cruise speed of `BRIDGE_SLICES × SLICE_MS` = 40 ms. These steps are part of the cross phase but are not adjusted; a correction 40 ms earlier or later makes no difference.

**S-curve:** the speed follows a smooth step (3p²−2p³) in the distance traveled, so the acceleration is zero at the beginning and end of the ramp — no torque shock at the transitions. Doesn't cost anything extra, because the table is generated in Python and then only played back by DMA. `ACCEL_CM_S2 = 55` determines the ramp *distance* (3.28 cm); the peak acceleration is 1.5× = 82 cm/s² = 0.084 g and the ramp *lasts* 0.55 s.

A movement shorter than 2 × 3.28 = 6.6 cm does not reach top speed and automatically gets a triangular profile.

#### Exact distance

Adjustment changes **when** steps occur, not **how many**. `committed` is kept for each engine: the sum of all written `repeat` values. The braking point is determined at `committed`, not at a measured position, so the **commanded average step total is exact** — regardless of when the control loop happens to call. The *physical* distance is not: microstepping accuracy, wheel slip, tire deformation and the calibration of `WHEEL_CIRC` are still above that. `repeat_A + repeat_B = 2 × base` applies to each slice, causing the center of the cart to move exactly `base` steps while the difference changes the course.

Both motors receive the same slice duration** (20 ms) and a different number of steps per slice; as a result, they remain synchronous in time (**calculated** rounding error < 20 µs at 20 ms; not yet measured with a logic analyzer).

#### Odometry — signed, because the counter SM does not know the DIR pin

The counter SMs count **STEP edges** and know nothing about the direction. A rough pulse counter is therefore not a position: when rotating on the spot, both counters increase positively while the wheels rotate in opposite directions. In addition to the monotonous pulse counter, each motor therefore maintains a **signed position** that takes the sign with each change of direction.

| Function | Meaning |
|---|---|
| `pio_pos1()` / `pio_pos2()` | monotone pulse counter (unsigned), used by `busy()` |
| `_Motor.travel()` | signed position in steps: forward positive, backward negative |
| `distance()` | `(travel_A + travel_B) / 2 × CM_PER_STEP` — a rotation gives ~0 cm, backwards counts negative |
| `heading()` | `(travel_A − travel_B) / STEPS_PER_DEG` — also works with a rotation at the position |

> **Note:** the counters count STEP pulses/commands, not guaranteed physical wheel movement. In the event of slip or a missed motor step, the odometry may therefore deviate. The GY9250 provides independent measurement of rotational speed and orientation, but not absolute linear X/Y position; linear slip of both wheels requires an external position reference to detect directly.

#### Course correction — cascade LDR + gyro

Change in direction comes from a **difference in number of steps** between the wheels. In fire-and-forget, where both engines are locked to the same total, a difference in speed gives a net **zero** change in course (the cart arcs and returns in the same direction). In the cruising phase this is not fixed at all, so a speed difference does integrate into a permanent change in course.

| Loop | Sensor | Frequency | Roll |
|---|---|---|---|
| Outside | LDR A/B difference | single Hz (1× per 5 slices) | determines **where** we should go; A ≈ B = right to the source. Provides the setpoint for the rotation speed |
| Inside | GY9250 gyro-Z | each slice (~50 Hz) | suppresses **disruptions**: bumps, grooves, uneven floor, wheel slip. Adjusts the difference between desired and measured rotational speed |

This is **not dual control**: the LDR determines the direction, the gyro only the interference suppression.

Pay attention to what the inner loop does and doesn't do. It compensates for the difference between desired and measured **turning speed**, so it dampens a disturbance *as long as it occurs*. It does not integrate an angular error, so the twist that comes out at the bottom of the line is not subsequently reversed; the LDR outer loop does that. Without LDR (`damp_yaw_rate()`) there is **no course keeping** — only damping, with permanent drift due to gyro bias. With a briefly covered light source, the cart continues to go approximately straight, but it does not return to the old course.

The **magnetometer/compass** is deliberately not used while driving - the stepper motors disturb the field (see the GY9250 stepper motor calibration). The compass is for the return journey, where an absolute heading is needed.

The **accelerometer** is not used for slip detection. That idea — "stepping without acceleration means slipping" — doesn't work: At constant speed, forward acceleration is zero by definition, so normal driving and full skidding look identical.

What it does contain is a **course tracking error** on gyro-Z: if the measured rotational speed persistently deviates from what was actually written, then `HeadingController.yaw_tracking_error` is set to `True`. That's a *clue*, not slip proof — control dynamics, gyro delay, saturation and wrong gain give the same picture. Linear slip (both wheels straight ahead) cannot be seen anyway; that requires an external position reference.

**Steering authority:** at a speed differential of ±20%, the turning speed is ±32 °/s; at ±5% this is ±8 °/s. Resolution 0.0063° (1 step difference). That 32 °/s applies **at top speed**: the authority is a fraction of the driving speed and therefore scales proportionally (at 5 cm/s still 8.4 °/s). `turn_authority_deg_s(rate)` calculates that and `Move()` sets the ceiling of `HeadingController`.

#### Why not vary the PIO clock

The alternative — modify `SMn_CLKDIV` at runtime — is deliberately **not** used, even though it is technically possible via `machine.mem32`:
- it is outside the data path, so out of sync with the segment boundaries;
- the step numbers are then no longer known exactly;
- the delay values are in PIO cycles, so a clock change rescales the ramp table along the way (and the acceleration scales by f²).

The clock divider remains usable as a global **speed override** (everything slower, e.g. near an obstacle).
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

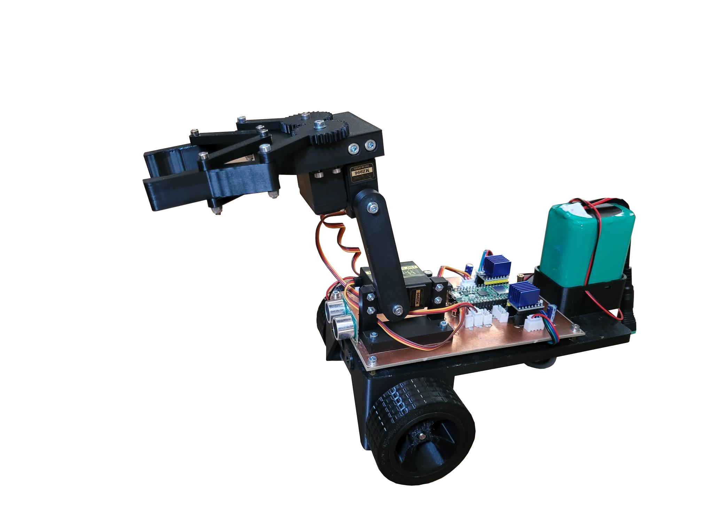
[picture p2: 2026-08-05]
hardware/Robot_carv1.2.png

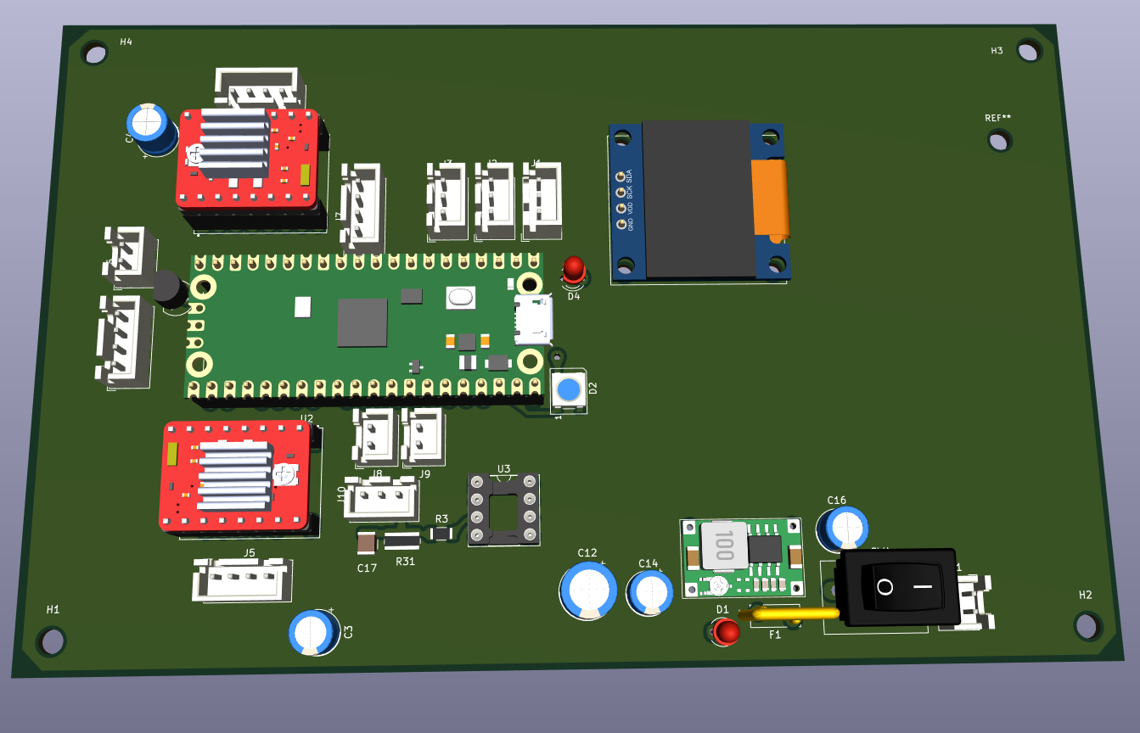
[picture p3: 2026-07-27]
hardware/KiCAD/DIY_CAR_pcb.png

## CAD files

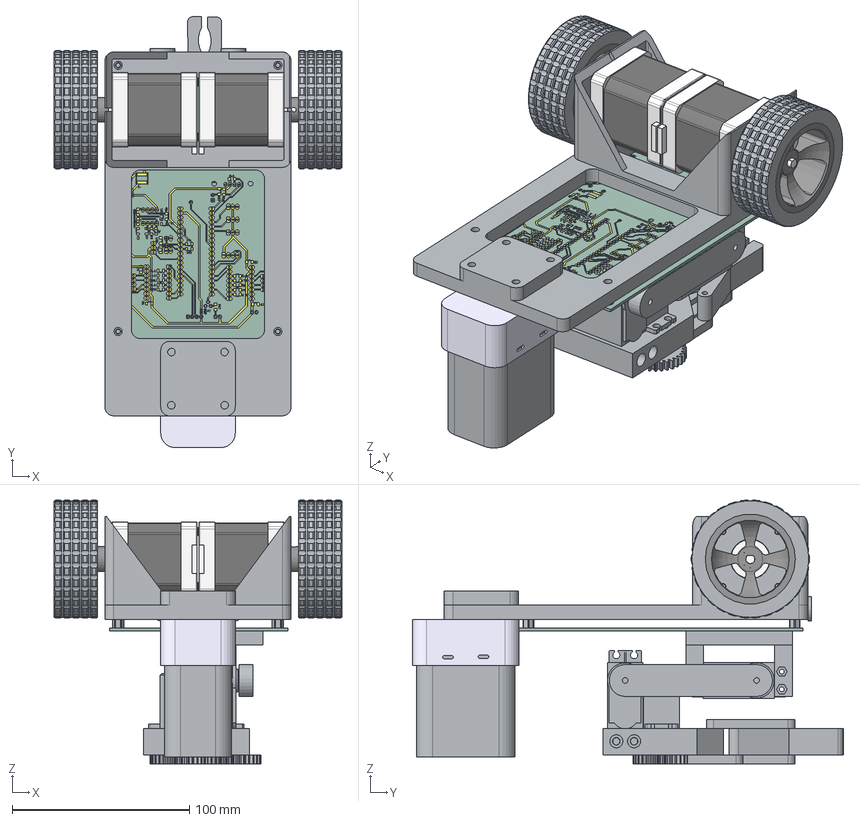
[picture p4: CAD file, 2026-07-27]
hardware/FreeCAD/assembly_all.step
162.0 x 242.8 x 148.7 mm
Lichaam x 16
Nema17 48 x 2
M3x8-Screw x 2
M3x8-Screw004 x 2
M3x8-Screw005 x 2
M3x8-Screw006 x 2
M3x5x6-Standoff x 4
DIY car 2_copper
DIY car 2_copper001
DIY car 2_copper002
DIY car 2_copper003
DIY car 2_copper004
DIY car 2_copper005
DIY car 2_copper006
DIY car 2_copper007
DIY car 2_copper008
DIY car 2_copper009
DIY car 2_copper010
DIY car 2_copper011
DIY car 2_copper012
DIY car 2_copper013
DIY car 2_copper014
DIY car 2_copper015
DIY car 2_copper016
DIY car 2_copper017
DIY car 2_copper018
DIY car 2_copper019
DIY car 2_copper020
DIY car 2_copper021
DIY car 2_copper022
DIY car 2_copper023
DIY car 2_copper024
DIY car 2_copper025
DIY car 2_copper026
DIY car 2_copper027
DIY car 2_copper028
DIY car 2_copper029
DIY car 2_copper030
DIY car 2_copper031
DIY car 2_copper032
DIY car 2_copper033
DIY car 2_copper034
DIY car 2_copper035
DIY car 2_copper036
DIY car 2_copper037
DIY car 2_copper038
DIY car 2_copper039
DIY car 2_copper040
DIY car 2_copper041
DIY car 2_copper042
DIY car 2_copper043
DIY car 2_copper044
DIY car 2_copper045
DIY car 2_copper046
DIY car 2_copper047
DIY car 2_copper048
DIY car 2_copper049
DIY car 2_copper050
DIY car 2_copper051
DIY car 2_copper052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

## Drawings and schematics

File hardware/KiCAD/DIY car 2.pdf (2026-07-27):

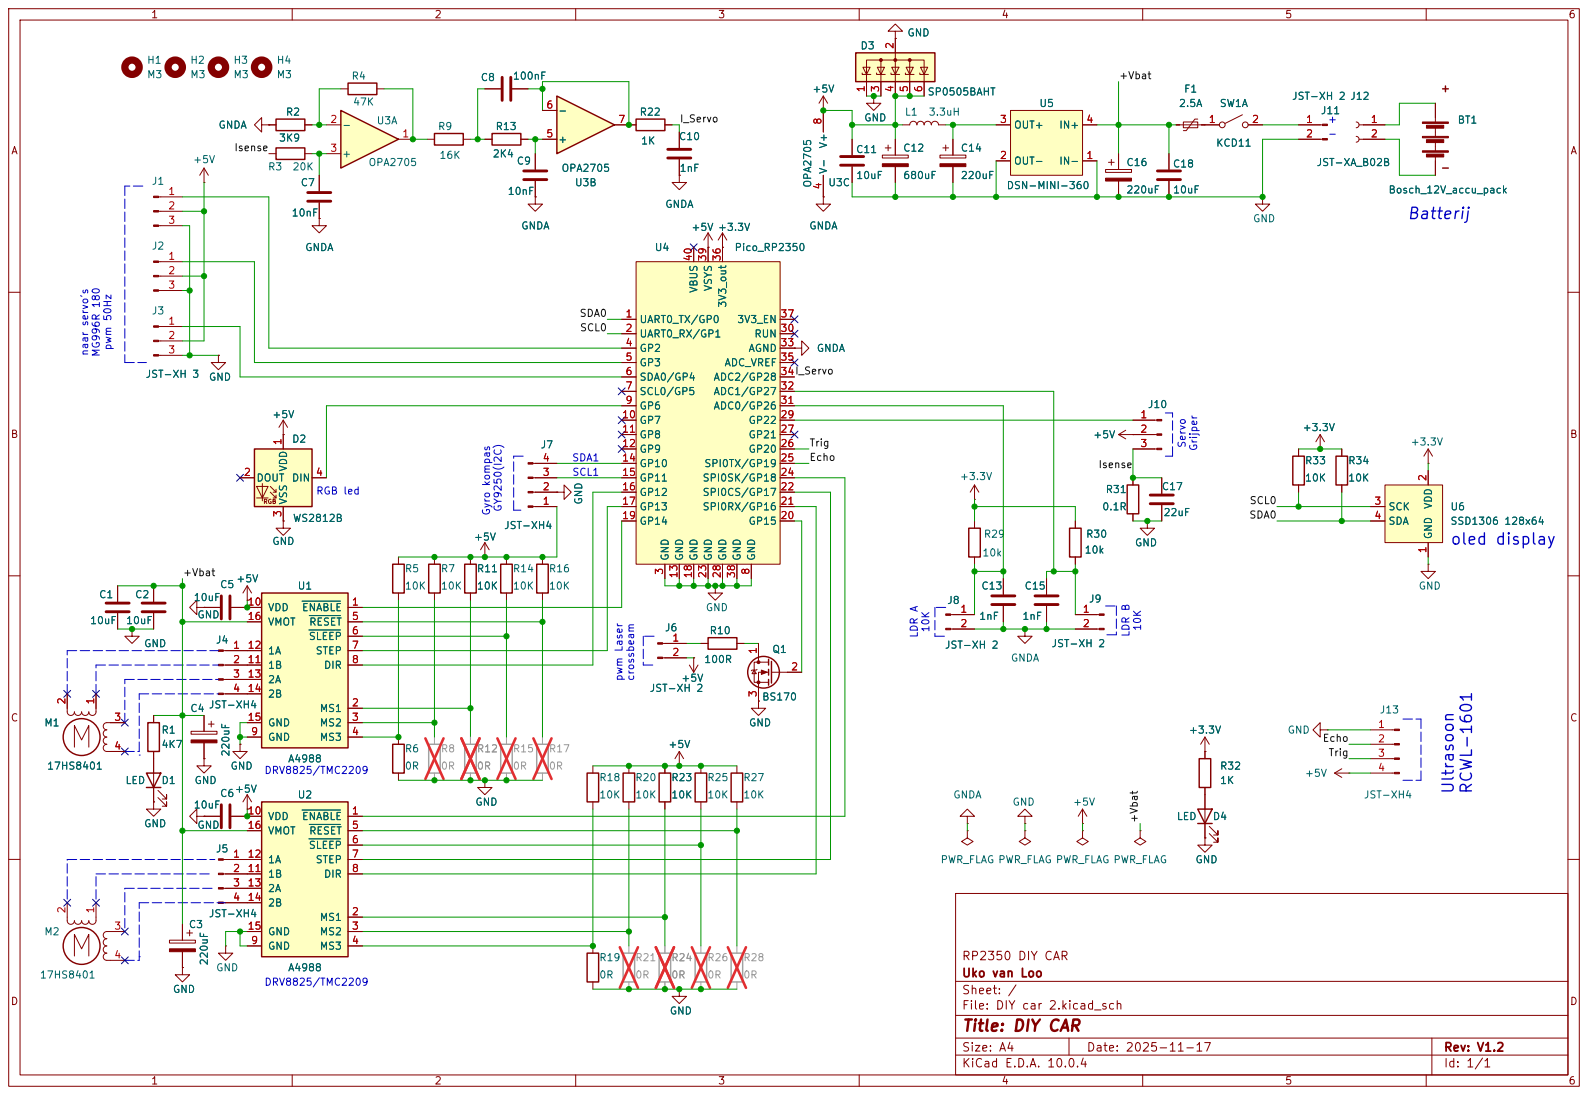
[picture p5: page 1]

Size: A4 | Rev: V1.2
KiCad E.D.A. 10.0.4 | Id: 1/1

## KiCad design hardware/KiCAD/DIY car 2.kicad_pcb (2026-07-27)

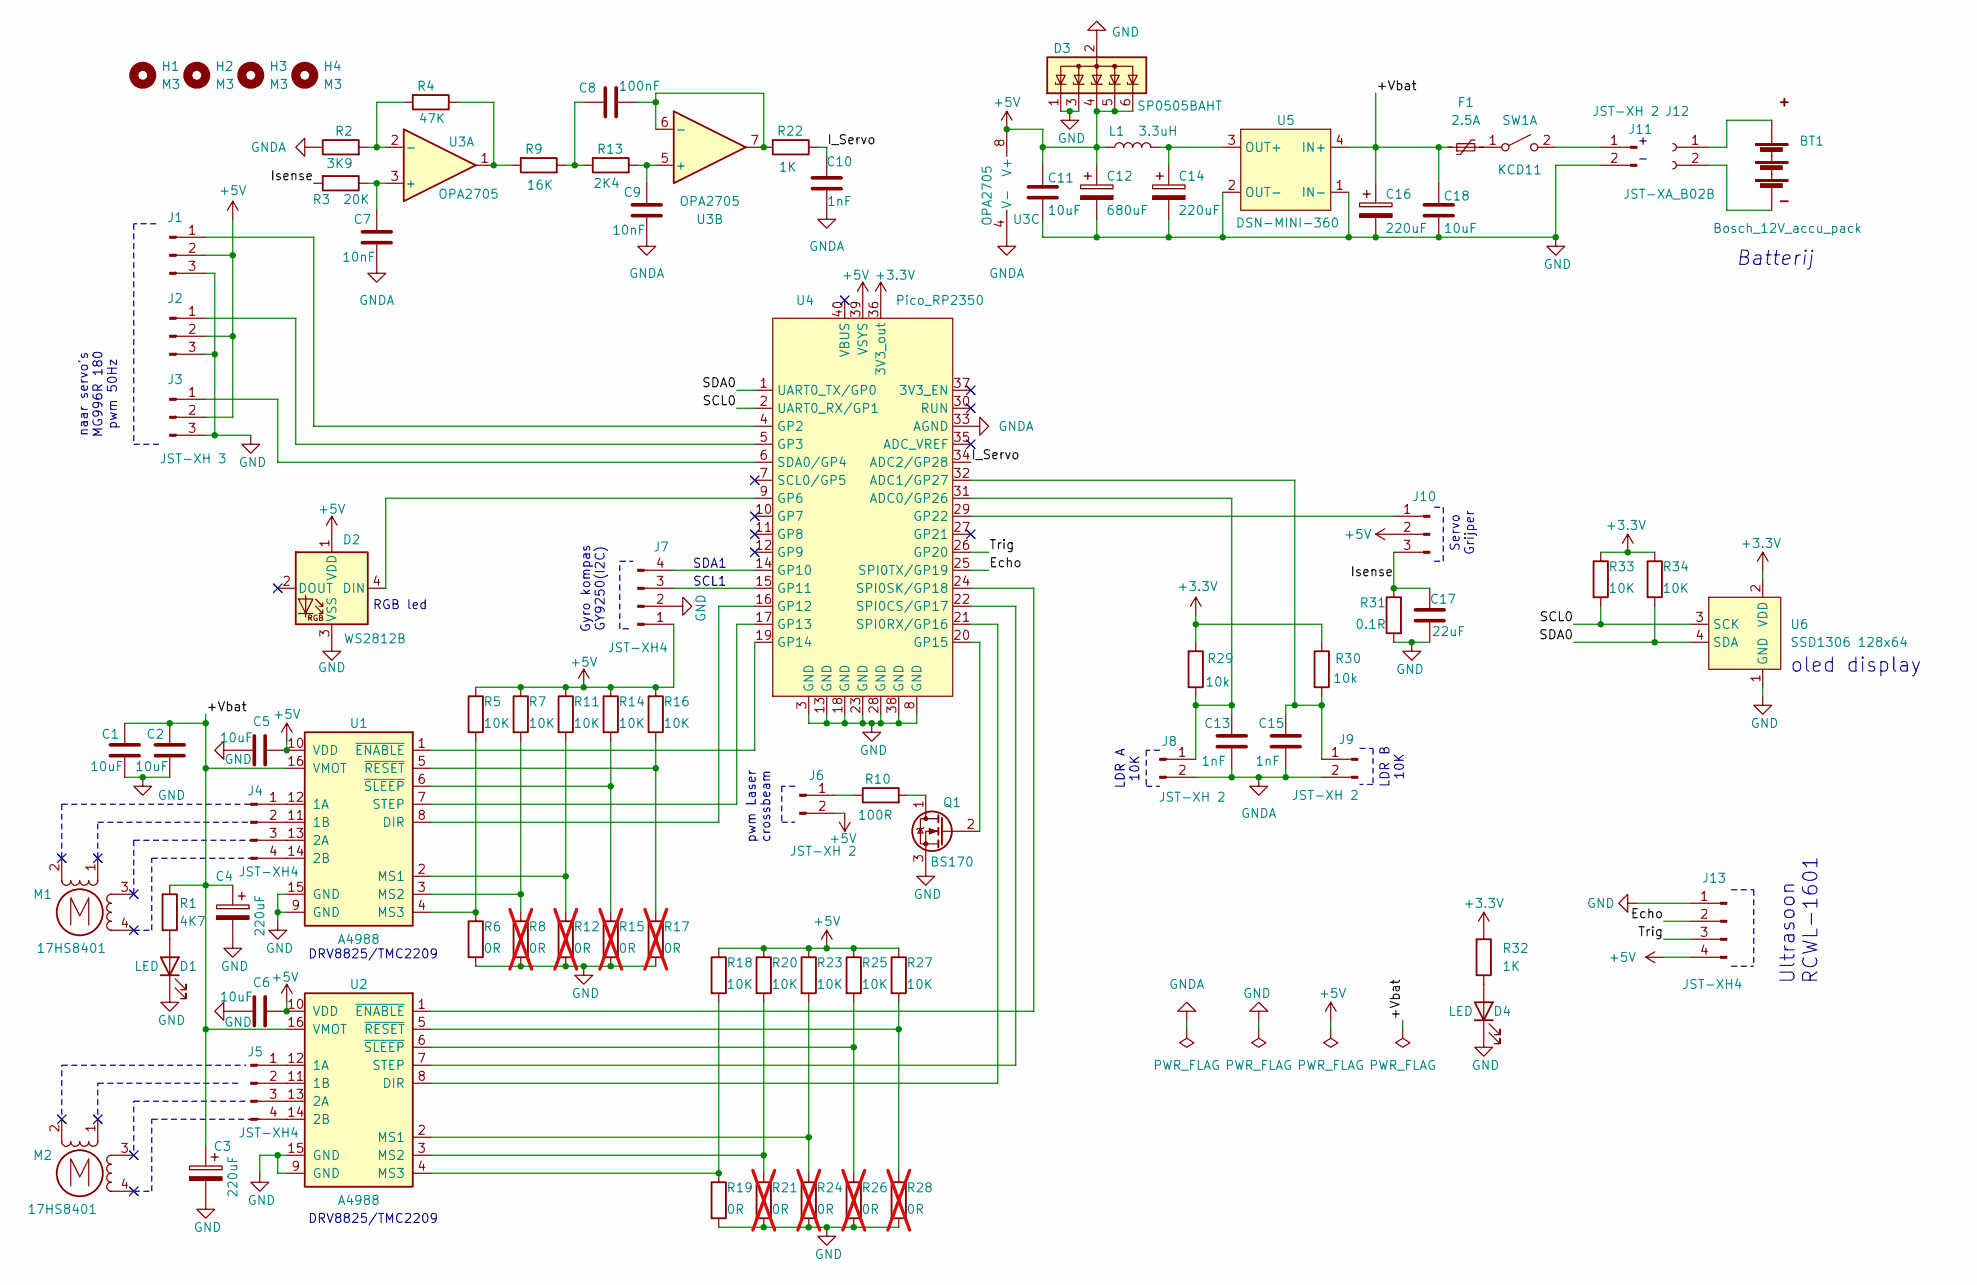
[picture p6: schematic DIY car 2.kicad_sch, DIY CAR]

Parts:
BT1: Bosch_12V_accu_pack; batterij houder bosch
C1, C2, C5, C6, C11, C18: 10uF; C_1206_3216Metric_Pad1.33x1.80mm_HandSolder
C3, C4, C14, C16: 220uF; CP_Radial_D6.3mm_P2.50mm
C7, C9: 10nF; C_1206_3216Metric_Pad1.33x1.80mm_HandSolder
C8: 100nF; C_1206_3216Metric_Pad1.33x1.80mm_HandSolder
C10, C13, C15: 1nF; C_1206_3216Metric_Pad1.33x1.80mm_HandSolder
C12: 680uF; CP_Radial_D8.0mm_P3.50mm
C17: 22uF; C_1210_3225Metric_Pad1.33x2.70mm_HandSolder
D1, D4: LED; LED_D3.0mm
D2: WS2812B; LED_WS2812B_PLCC4_5.0x5.0mm_P3.2mm
D3: SP0505BAHT; SOT-23-6
F1: 2.5A; Fuse_Bourns_MF-RG300
H1, H2, H3, H4: M3; MountingHole_3.5mm
J1, J2, J3, J10: JST-XH 3; JST_XH_B3B-XH-A_1x03_P2.50mm_Vertical
J4, J5, J7, J13: JST-XH4; JST_XH_B4B-XH-A_1x04_P2.50mm_Vertical
J6, J8, J9, J11: JST-XH 2; JST_XH_B2B-XH-AM_1x02_P2.50mm_Vertical_CNC
J12: JST-XA_B02B; JST_XA_B02B-XASK-1-A_1x02_P2.50mm_Vertical
L1: 3.3uH; L_APV_ANR6045
M1, M2: 17HS8401
Q1: BS170; TO-92_Inline
R1: 4K7; R_1206_3216Metric_Pad1.30x1.75mm_HandSolder
R2: 3K9; R_1206_3216Metric_Pad1.30x1.75mm_HandSolder
R3: 20K; R_1206_3216Metric_Pad1.30x1.75mm_HandSolder
R4: 47K; R_1206_3216Metric_Pad1.30x1.75mm_HandSolder
R5, R7, R11, R14, R16, R18, R20, R23, R25, R27, R33, R34: 10K; R_1206_3216Metric_Pad1.30x1.75mm_HandSolder
R6, R19: 0R; R_1206_3216Metric_Pad1.30x1.75mm_HandSolder
R8, R12, R15, R17, R21, R24, R26, R28: 0R; R_1206_3216Metric_Pad1.30x1.75mm_HandSolder; not fitted
R9: 16K; R_1206_3216Metric_Pad1.30x1.75mm_HandSolder
R10: 100R; R_1206_3216Metric_Pad1.30x1.75mm_HandSolder
R13: 2K4; R_1206_3216Metric_Pad1.30x1.75mm_HandSolder
R22, R32: 1K; R_1206_3216Metric_Pad1.30x1.75mm_HandSolder
R29, R30: 10k; R_1206_3216Metric_Pad1.30x1.75mm_HandSolder
R31: 0.1R; R_1020_2550Metric_Pad1.33x5.20mm_HandSolder
SW1: KCD11
U1, U2: A4988
U3: OPA2705; DIP-8_W7.62mm_Socket_LongPads
U4: Pico_RP2350; DIP-40_700mil
U5: DSN-MINI-360
U6: SSD1306 128x64; OLED 0.96 I2C

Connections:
+3.3V: R29.1, R30.1, R32.1, R33.1, R34.1, U4.36 (3V3_out), U6.2 (VDD)
+5V: C5.2, C6.2, C11.2, C12.1, D2.1 (VDD), D3.4 (K), D3.5 (K), D3.6 (K), J1.2, J2.2, J3.2, J6.2, J7.1, J10.2, J13.4, L1.1, R5.1, R7.1, R11.1, R14.1, R16.1, R18.1, R20.1, R23.1, R25.1, R27.1, U1.10 (VDD), U2.10 (VDD), U3.8 (V+), U4.39 (VSYS)
/+Vbat: C1.2, C2.2, C3.1, C4.1, C16.1, C18.2, F1.1, R1.1, U1.16 (VMOT), U2.16 (VMOT), U5.4 (IN+)
/Echo: J13.2, U4.25 (SPI0TX/GP19)
/I_Servo: C10.2, R22.1, U4.34 (ADC2/GP28)
/Isense: C17.1, J10.3, R3.2, R31.1
/SCL0: R33.2, U4.2 (UART0_RX/GP1), U6.3 (SCK)
/SDA0: R34.2, U4.1 (UART0_TX/GP0), U6.4 (SDA)
/Trig: J13.3, U4.26 (GP20)
GND: C1.1, C2.1, C3.2, C4.2, C5.1, C6.1, C11.1, C12.2, C14.2, C16.2, C17.2, C18.1, D1.1 (K), D2.3 (VSS), D3.1 (K), D3.2 (A), D3.3 (K), D4.1 (K), J1.3, J2.3, J3.3, J7.2, J11.2, J13.1, Q1.3 (S), R6.2, R8.2, R12.2, R15.2, R17.2, R19.2, R21.2, R24.2, R26.2, R28.2, R31.2, U1.9 (GND), U1.15 (GND), U2.9 (GND), U2.15 (GND), U4.3 (GND), U4.8 (GND), U4.13 (GND), U4.18 (GND), U4.23 (GND), U4.28 (GND), U4.38 (GND), U5.1 (IN-), U5.2 (OUT-), U6.1 (GND)
GNDA: C7.1, C9.1, C10.1, C13.1, C15.1, J8.2, J9.2, R2.1, U3.4 (V-), U4.33 (AGND)
unnamed: BT1.1 (+), J12.1
unnamed: BT1.2 (-), J12.2
unnamed: C8.1, R9.1, R13.2
unnamed: D1.2 (A), R1.2
unnamed: D2.4 (DIN), U4.9 (GP6)
unnamed: D4.2 (A), R32.2
unnamed: J1.1, U4.4 (GP2)
unnamed: J2.1, U4.5 (GP3)
unnamed: J3.1, U4.6 (SDA0/GP4)
unnamed: J4.1, U1.12 (1A)
unnamed: J4.2, U1.11 (1B)
unnamed: J4.3, U1.13 (2A)
unnamed: J4.4, U1.14 (2B)
unnamed: J5.1, U2.12 (1A)
unnamed: J5.2, U2.11 (1B)
unnamed: J5.3, U2.13 (2A)
unnamed: J5.4, U2.14 (2B)
unnamed: J6.1, R10.1
unnamed: J7.3, U4.15 (GP11)
unnamed: J7.4, U4.14 (GP10)
unnamed: C13.2, J8.1, R29.2, U4.31 (ADC0/GP26)
unnamed: C15.2, J9.1, R30.2, U4.32 (ADC1/GP27)
unnamed: J10.1, U4.29 (GP22)
unnamed: J11.1, SW1.2 (B)
unnamed: Q1.1 (D), R10.2
unnamed: Q1.2 (G), U4.20 (GP15)
unnamed: R4.1, R9.2, U3.1
unnamed: F1.2, SW1.1 (A)
unnamed: U1.8 (DIR), U4.16 (GP12)
unnamed: R11.2, R12.1, U1.2 (MS1)
unnamed: R7.2, R8.1, U1.3 (MS2)
unnamed: R5.2, R6.1, U1.4 (MS3)
unnamed: U1.7 (STEP), U4.17 (GP13)
unnamed: U1.1 (~ENABLE), U4.19 (GP14)
unnamed: R16.2, R17.1, U1.5 (~RESET)
unnamed: R14.2, R15.1, U1.6 (~SLEEP)
unnamed: U2.8 (DIR), U4.21 (SPI0RX/GP16)
unnamed: R23.2, R24.1, U2.2 (MS1)
unnamed: R20.2, R21.1, U2.3 (MS2)
unnamed: R18.2, R19.1, U2.4 (MS3)
unnamed: U2.7 (STEP), U4.22 (SPI0CS/GP17)
unnamed: U2.1 (~ENABLE), U4.24 (SPI0SK/GP18)
unnamed: R27.2, R28.1, U2.5 (~RESET)
unnamed: R25.2, R26.1, U2.6 (~SLEEP)
unnamed: C7.2, R3.1, U3.3 (+)
unnamed: R2.2, R4.2, U3.2 (-)
unnamed: C9.2, R13.1, U3.5 (+)
unnamed: C8.2, R22.2, U3.6 (-), U3.7
unnamed: C14.1, L1.2, U5.3 (OUT+)

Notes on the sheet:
oled display
LDR B 10K
DRV8825/TMC2209
SCL1
pwm Laser crossbeam
Ultrasoon RCWL-1601
Gyro kompas GY9250(I2C)
naar servo's MG996R 180 pwm 50Hz
RGB led
SDA1
Servo Grijper
LDR A 10K
Batterij

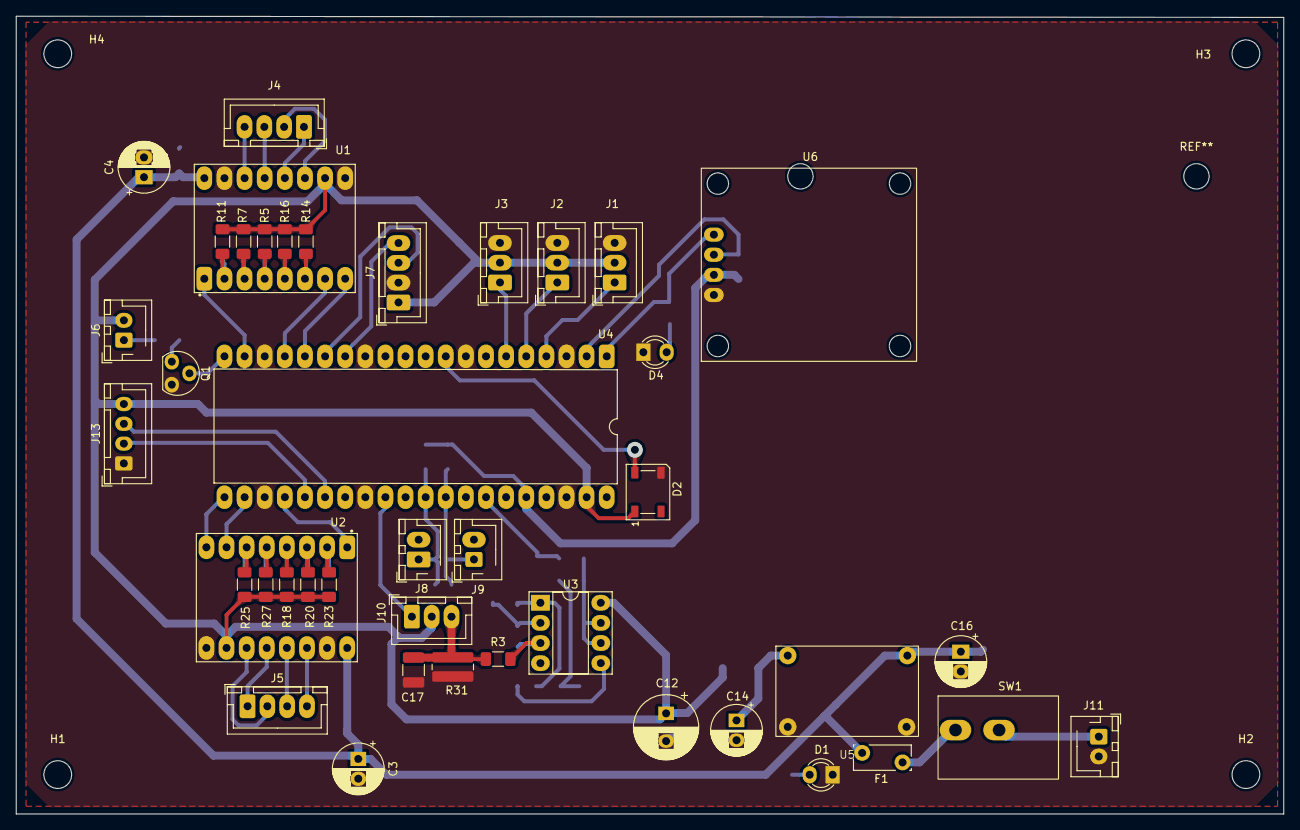
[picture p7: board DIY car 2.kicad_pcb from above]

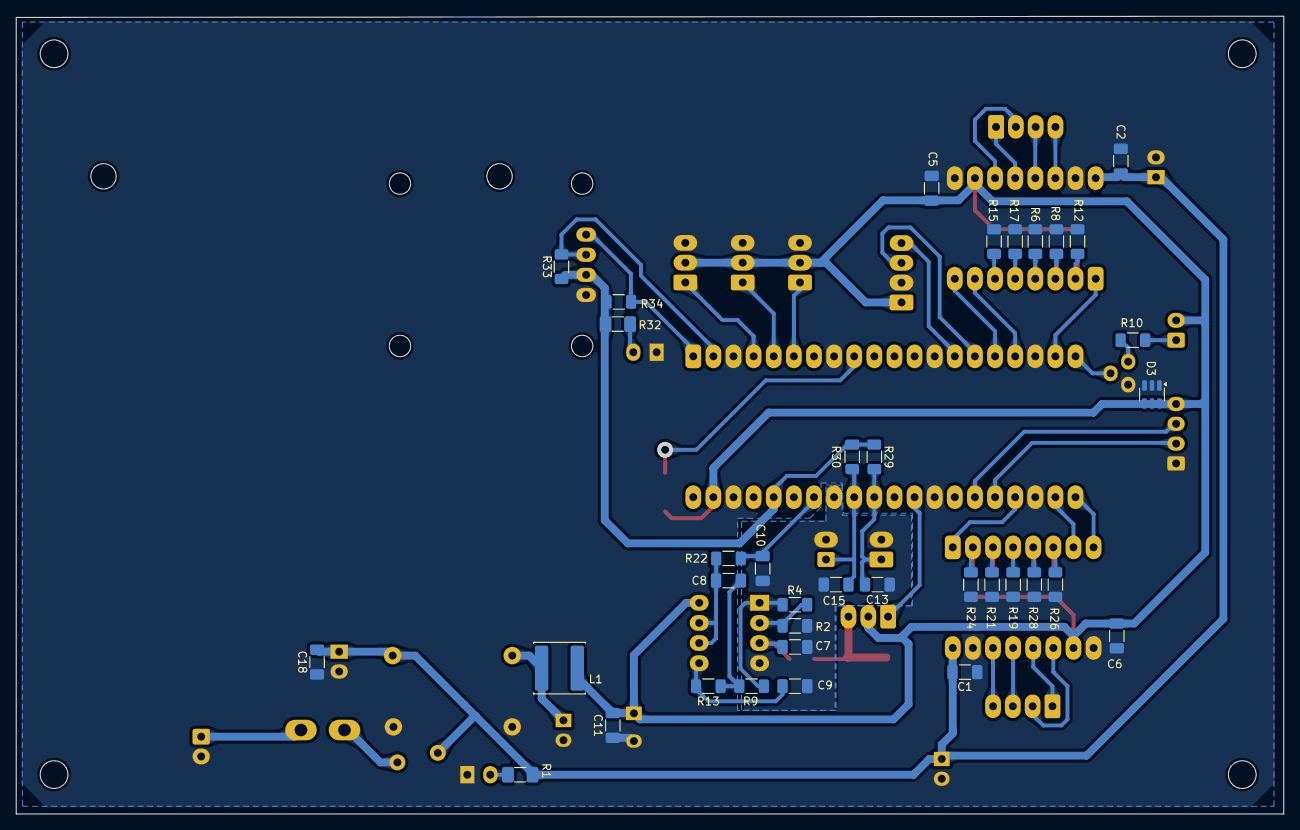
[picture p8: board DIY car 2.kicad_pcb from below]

Board: 2 copper layers, 160.0 x 100.7 mm, 82 parts (36 on the bottom side), 58 nets.

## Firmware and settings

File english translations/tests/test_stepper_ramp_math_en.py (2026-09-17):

# ================================================================
# tests/test_stepper_ramp_math.py
#
# Pure-Python tests for lib/stepper/stepper_ramp.py. NO hardware needed:
# machine and rp2 are stubbed, so this also runs on PC with CPython.
#
#     python3 tests/test_stepper_ramp_math.py
#
# Covered: plan(), ramp_words(), profile_words(), zero distances, boundary values,
# input validation, the slice arithmetic, and the DMA -> CPU transition in Move
# (there was a bug: the CPU was not allowed to push while the DMA was still writing).
#
# Regressions guarded here because they were previously faulty:
#   - finish() during the ramp-up DMA left busy() forever True (committed counted
#     the entire ramp-up, while the truncated DMA never sent out those steps);
#   - a new Move() during an ongoing movement changed DIR and the counters
#     without stopping first;
#   - rotate_deg(+90) gave heading() = -90: the rotation direction was opposite
#     to the odometry and the correction.
# ================================================================

import sys
import os

sys.path.insert(0, os.path.join(os.path.dirname(os.path.abspath(__file__)),
                                "..", "lib", "stepper"))

_fails = []


def check(name, condition, detail=""):
    if condition:
        print("  ok   %s" % name)
    else:
        print("  FAIL %s %s" % (name, detail))
        _fails.append(name)


# ----------------------------------------------------------------
# Stubs for machine and rp2
# ----------------------------------------------------------------
class _Types:
    pass


class _FakePin:
    OUT = 1
    IN = 0

    def __init__(self, n, mode=None):
        self.n = n
        self._v = 0

    def value(self, v=None):
        if v is None:
            return self._v
        self._v = v


class _FakeSM:
    """Generates nothing, but keeps track of the FIFO and a simulated pulse counter."""

    def __init__(self, sm_id, prog, freq=None, **kw):
        self.sm_id = sm_id
        self.fifo = []
        self.sim_pulses = 0

    def active(self, v=None):
        return 1

    def put(self, w):
        self.fifo.append(w)

    def exec(self, instr):
        # reset_pos() resets the hardware counter; the stub must do that too,
        # otherwise pulses leak from one test to the next.
        if "mov(y, osr)" in instr:
            self.sim_pulses = 0

    def get(self):
        # pulses() calculates 0xFFFFFFFF - y, so return y
        return 0xFFFFFFFF - self.sim_pulses

    def tx_fifo(self):
        return len(self.fifo)

    def init(self, prog, freq=None, **kw):
        self.fifo = []


class _FakeDMA:
    """Holds the words still to be written; active() is True as long as they exist."""

    def __init__(self):
        self.pending = []
        self.target = None

    def pack_ctrl(self, **kw):
        return 0

    def config(self, read=None, write=None, count=None, ctrl=None, trigger=False):
        self.pending = list(read)
        self.target = write

    def active(self, v=None):
        if v is not None:
            self.pending = []
            return None
        return len(self.pending) > 0


class _FakePIO:
    OUT_LOW = 0
    OUT_HIGH = 1
    SHIFT_RIGHT = 1
    SHIFT_LEFT = 0
    JOIN_NONE = 0
    JOIN_TX = 1
    JOIN_RX = 2


def _fake_asm_pio(*a, **kw):
    def deco(fn):
        return fn          # the body is never executed
    return deco


_machine = _Types()
_machine.Pin = _FakePin
_machine.mem32 = {}
sys.modules["machine"] = _machine

_rp2 = _Types()
_rp2.PIO = _FakePIO
_rp2.StateMachine = _FakeSM
_rp2.DMA = _FakeDMA
_rp2.asm_pio = _fake_asm_pio
sys.modules["rp2"] = _rp2

import stepper_ramp as sr          # noqa: E402


# ----------------------------------------------------------------
# Helper functions
# ----------------------------------------------------------------
def decode(w):
    """FIFO word -> (number of steps, delay)."""
    return (w & 0xFFFF) + 1, w >> 16


def total(words):
    return sum(decode(w)[0] for w in words)


def drain(motor):
    """Simulate the PIO executing everything that has been offered."""
    while motor.dma.pending:
        motor.sm.fifo.append(motor.dma.pending.pop(0))
    n = 0
    while motor.sm.fifo:
        n += decode(motor.sm.fifo.pop(0))[0]
    motor.cnt.sim_pulses += n


def drain_words(motor, k):
    """Simulate the PIO executing exactly k words (DMA shifts through first).

    Needed to be able to intervene MIDWAY through a DMA transfer; drain() always
    finishes everything and therefore never gets to this.
    """
    for _ in range(k):
        if motor.dma.pending:
            motor.sm.fifo.append(motor.dma.pending.pop(0))
        if not motor.sm.fifo:
            return
        motor.cnt.sim_pulses += decode(motor.sm.fifo.pop(0))[0]


def fresh():
    """Completely clean starting state, as if the cart has just booted up."""
    sr.halt()                       # committed back to the pulse position
    for m in sr._MOTORS:
        m.sm.fifo = []
        m.dma.pending = []
        m.cnt.sim_pulses = 0
        m.committed = 0
    sr.reset_PIO_distance()


def run_to_end(mv, limit=200000):
    """Run a Move entirely to the end. False = did not finish within the limit."""
    for _ in range(limit):
        for m in sr._MOTORS:
            drain(m)
        if not mv.service():
            return True
    return False


# ----------------------------------------------------------------
print("\n--- ramp_words: exact step count and valid fields ---")
r0 = sr.rate_of(sr.V_START_CM_S)
r1 = sr.rate_of(sr.V_MAX_CM_S)

for n in (0, 1, 2, 3, 7, 100, 255, 256, 257, 2200, 65536, 70000):
    w = sr.ramp_words(n, r0, r1)
    if n <= 0:
        check("n=%d -> empty list" % n, w == [])
        continue
    check("n=%d sum matches" % n, total(w) == n, "(%d)" % total(w))
    reps = [decode(x)[0] for x in w]
    dels = [decode(x)[1] for x in w]
    check("n=%d fields within range" % n,
          all(1 <= r <= 65536 for r in reps) and all(1 <= d <= 65535 for d in dels))
    freqs = [sr.F_PIO / (d + sr.CYCLES_FIXED) for d in dels]
    check("n=%d speed monotonically increasing" % n,
          all(freqs[i] <= freqs[i + 1] + 1e-9 for i in range(len(freqs) - 1)))

w = sr.ramp_words(2200, r1, r0)
dels = [decode(x)[1] for x in w]
freqs = [sr.F_PIO / (d + sr.CYCLES_FIXED) for d in dels]
check("descending ramp is monotonically decreasing",
      all(freqs[i] >= freqs[i + 1] - 1e-9 for i in range(len(freqs) - 1)))
check("descending ramp starts at top speed",
      abs(freqs[0] * sr.CM_PER_STEP - sr.V_MAX_CM_S) < 0.5,
      "(%.2f cm/s)" % (freqs[0] * sr.CM_PER_STEP))

# ----------------------------------------------------------------
print("\n--- plan(): triangle, lower bound and zero distance ---")
n_ramp, a, b = sr.plan(0, sr.V_MAX_CM_S)
check("zero distance -> no ramp", n_ramp == 0)
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

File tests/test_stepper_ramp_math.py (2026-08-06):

# ================================================================
# tests/test_stepper_ramp_math.py
#
# Pure-Python tests voor lib/stepper/stepper_ramp.py. GEEN hardware nodig:
# machine en rp2 worden gestubd, dus dit draait ook op de PC met CPython.
#
#     python3 tests/test_stepper_ramp_math.py
#
# Gedekt: plan(), ramp_words(), profile_words(), nulafstanden, grenswaarden,
# invoervalidatie, de slice-rekenkunde, en de DMA -> CPU overgang in Move
# (daar zat een fout: de CPU mocht niet pushen terwijl de DMA nog schreef).
#
# Regressies die hier bewaakt worden omdat ze eerder fout waren:
#   - finish() tijdens de opramp-DMA liet busy() eeuwig True (committed telde
#     de hele opramp, terwijl de afgekapte DMA die stappen nooit uitstuurde);
#   - een nieuwe Move() tijdens een lopende beweging zette DIR en de tellers om
#     zonder eerst te stoppen;
#   - rotate_deg(+90) gaf heading() = -90: de draairichting stond tegengesteld
#     aan de odometrie en aan de bijsturing.
# ================================================================

import sys
import os

sys.path.insert(0, os.path.join(os.path.dirname(os.path.abspath(__file__)),
                                "..", "lib", "stepper"))

_fails = []


def check(naam, conditie, detail=""):
    if conditie:
        print("  ok   %s" % naam)
    else:
        print("  FOUT %s %s" % (naam, detail))
        _fails.append(naam)


# ----------------------------------------------------------------
# Stubs voor machine en rp2
# ----------------------------------------------------------------
class _Types:
    pass


class _FakePin:
    OUT = 1
    IN = 0

    def __init__(self, n, mode=None):
        self.n = n
        self._v = 0

    def value(self, v=None):
        if v is None:
            return self._v
        self._v = v


class _FakeSM:
    """Genereert niets, maar houdt de FIFO en een gesimuleerde pulsteller bij."""

    def __init__(self, sm_id, prog, freq=None, **kw):
        self.sm_id = sm_id
        self.fifo = []
        self.sim_pulses = 0

    def active(self, v=None):
        return 1

    def put(self, w):
        self.fifo.append(w)

    def exec(self, instr):
        # reset_pos() zet de hardwareteller terug; dat moet de stub ook doen,
        # anders lekken pulsen van de ene test naar de volgende.
        if "mov(y, osr)" in instr:
            self.sim_pulses = 0

    def get(self):
        # pulses() rekent 0xFFFFFFFF - y, dus geef y terug
        return 0xFFFFFFFF - self.sim_pulses

    def tx_fifo(self):
        return len(self.fifo)

    def init(self, prog, freq=None, **kw):
        self.fifo = []


class _FakeDMA:
    """Houdt de nog te schrijven woorden vast; active() is True zolang die er zijn."""

    def __init__(self):
        self.pending = []
        self.target = None

    def pack_ctrl(self, **kw):
        return 0

    def config(self, read=None, write=None, count=None, ctrl=None, trigger=False):
        self.pending = list(read)
        self.target = write

    def active(self, v=None):
        if v is not None:
            self.pending = []
            return None
        return len(self.pending) > 0


class _FakePIO:
    OUT_LOW = 0
    OUT_HIGH = 1
    SHIFT_RIGHT = 1
    SHIFT_LEFT = 0
    JOIN_NONE = 0
    JOIN_TX = 1
    JOIN_RX = 2


def _fake_asm_pio(*a, **kw):
    def deco(fn):
        return fn          # de body wordt nooit uitgevoerd
    return deco


_machine = _Types()
_machine.Pin = _FakePin
_machine.mem32 = {}
sys.modules["machine"] = _machine

_rp2 = _Types()
_rp2.PIO = _FakePIO
_rp2.StateMachine = _FakeSM
_rp2.DMA = _FakeDMA
_rp2.asm_pio = _fake_asm_pio
sys.modules["rp2"] = _rp2

import stepper_ramp as sr          # noqa: E402


# ----------------------------------------------------------------
# Hulpfuncties
# ----------------------------------------------------------------
def decode(w):
    """FIFO-woord -> (aantal stappen, delay)."""
    return (w & 0xFFFF) + 1, w >> 16


def totaal(words):
    return sum(decode(w)[0] for w in words)


def drain(motor):
    """Simuleer dat de PIO alles uitvoert wat aangeboden is."""
    while motor.dma.pending:
        motor.sm.fifo.append(motor.dma.pending.pop(0))
    n = 0
    while motor.sm.fifo:
        n += decode(motor.sm.fifo.pop(0))[0]
    motor.cnt.sim_pulses += n


def drain_words(motor, k):
    """Simuleer dat de PIO precies k woorden uitvoert (DMA schuift eerst door).

    Nodig om MIDDEN in een DMA-transfer te kunnen ingrijpen; drain() maakt
    altijd alles af en komt daar dus nooit aan toe.
    """
    for _ in range(k):
        if motor.dma.pending:
            motor.sm.fifo.append(motor.dma.pending.pop(0))
        if not motor.sm.fifo:
            return
        motor.cnt.sim_pulses += decode(motor.sm.fifo.pop(0))[0]


def fresh():
    """Volledig schone begintoestand, alsof de kar net is opgestart."""
    sr.halt()                       # committed terug naar de pulsstand
    for m in sr._MOTORS:
        m.sm.fifo = []
        m.dma.pending = []
        m.cnt.sim_pulses = 0
        m.committed = 0
    sr.reset_PIO_distance()


def run_to_end(mv, limiet=200000):
    """Draai een Move helemaal uit. False = niet binnen de limiet geeindigd."""
    for _ in range(limiet):
        for m in sr._MOTORS:
            drain(m)
        if not mv.service():
            return True
    return False


# ----------------------------------------------------------------
print("\n--- ramp_words: exact stappenaantal en geldige velden ---")
r0 = sr.rate_of(sr.V_START_CM_S)
r1 = sr.rate_of(sr.V_MAX_CM_S)

for n in (0, 1, 2, 3, 7, 100, 255, 256, 257, 2200, 65536, 70000):
    w = sr.ramp_words(n, r0, r1)
    if n <= 0:
        check("n=%d -> lege lijst" % n, w == [])
        continue
    check("n=%d som klopt" % n, totaal(w) == n, "(%d)" % totaal(w))
    reps = [decode(x)[0] for x in w]
    dels = [decode(x)[1] for x in w]
    check("n=%d velden binnen bereik" % n,
          all(1 <= r <= 65536 for r in reps) and all(1 <= d <= 65535 for d in dels))
    freqs = [sr.F_PIO / (d + sr.CYCLES_FIXED) for d in dels]
    check("n=%d snelheid monotoon stijgend" % n,
          all(freqs[i] <= freqs[i + 1] + 1e-9 for i in range(len(freqs) - 1)))

w = sr.ramp_words(2200, r1, r0)
dels = [decode(x)[1] for x in w]
freqs = [sr.F_PIO / (d + sr.CYCLES_FIXED) for d in dels]
check("aflopende ramp is monotoon dalend",
      all(freqs[i] >= freqs[i + 1] - 1e-9 for i in range(len(freqs) - 1)))
check("aflopende ramp begint op topsnelheid",
      abs(freqs[0] * sr.CM_PER_STEP - sr.V_MAX_CM_S) < 0.5,
      "(%.2f cm/s)" % (freqs[0] * sr.CM_PER_STEP))

# ----------------------------------------------------------------
print("\n--- plan(): driehoek, ondergrens en nulafstand ---")
n_ramp, a, b = sr.plan(0, sr.V_MAX_CM_S)
check("nulafstand -> geen ramp", n_ramp == 0)
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

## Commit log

2026-06-09 Initial project setup: DIY robot car MicroPython RP2350
    Modules voor stepper (PIO), servo (PI stroomregeling), ultrasoonsensor (PIO) en LDR-scan.
    GPIO-pinout voor Revisie 2 (RP2350/TMC2209). Documentatie in README en hardware/gpio_pinout.md.
2026-07-09 Reorganize lib modules into per-component folders, add GY9250/display/laser groundwork
    Move stepper, servo, ultrasoon and LDR-scan modules into their own lib/
    subfolders and add the vendored GY9250 compass driver plus SSD1306 display
    driver. Introduce globale_specificatie.md and "te doen.md" as the living
    spec/roadmap, fix typos and internal inconsistencies (grijper is servo 4 on
    GPIO22, servo 3/GPIO4 is an optional unused connector; SM8 PIO split for
    ldr-scan already resolves the SM4 conflict), and rename GY9250 calibration
    scripts to remove spaces from filenames.
2026-07-10 Fix broken GY9250 scripts and add display-based hardware tests
    - Remove leftover markdown code-fence characters that made GY9250_basic.py,
    GY9250_fusion.py, Calibrate_GY9250.py, automatische_calibratie_magnetische_verstoring.py
    and deltat.py invalid Python (SyntaxError on import).
    - Restore fusion.py with an actual Fusion class (complementary filter with
    tilt compensation); it previously contained a duplicate of the basic
    compass script, breaking GY9250_fusion.py's `from fusion import Fusion`.
    - Fix Calibrate_GY9250.py to perform actual magnetometer calibration
    instead of duplicating the runtime compass script.
    - Correct I2C pins/bus to GPIO10 (SDA1) / GPIO11 (SCL1) across all scri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
    [test_gy9250_auto_calibrate.py, test_gy9250_basic.py, test_gy9250_calibrate.py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]
2026-07-10 Add hardware test scripts for display, LDR, servo, ultrasoon, and stepper
    Each script exercises one lib/ module standalone (matching tests/test_all.py's
    style) and shows live measured/set values on the SSD1306 OLED (I2C0, GPIO0/1)
    alongside console output:
    - test_display.py: simple text + live counter, plus an I2C address scan.
    - test_ldr.py: measured voltage on both LDR channels.
    - test_servo.py: moves each servo to 50% of travel (90 deg) then a small
    step, restoring original rest positions even if interrupted mid-run.
    - test_ultrasoon.py: live measured distance (ok/timeout/overflow).
    - test_stepper.py: exercises s1/s2/mov/rotate/enable/disable/status/
    reset_PIO_distance, showing target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
    [test_display.py, test_ldr.py, test_servo.py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]
2026-07-10 Add hardware test script for WS2812B RGB LED
    Cycles red, green, and blue at 50% brightness, then ramps white from
    5% to 60% brightness. Shows the active color/percentage and RGB byte
    values on the SSD1306 OLED alongside console output, and always turns
    the LED off on exit (including Ctrl-C).
2026-07-10 Remove unused packaging files from lib/GY9250
    Makefile, setup.py, and setup.cfg are leftovers from the upstream
    tuupola/micropython-mpu9250 PyPI package (macOS ampy sync paths,
    setuptools packaging). Nothing in this project references them; the
    driver modules are imported directly as lib/ files.
2026-07-10 Tune GY9250 auto-calibrate and LDR test scripts on real hardware
    - test_gy9250_auto_calibrate.py: throttle OLED updates to every 10th
    sample (framebuffer push over I2C was slowing down sampling), widen
    the calibration spin distance, and tighten the display formatting.
    - test_ldr.py: drop the ldr_scan_isr import in favor of local pin
    constants, and construct ADC directly from the GPIO number.
    [test_gy9250_auto_calibrate.py, test_ldr.py]
2026-07-10 Update project docs to match implementation status
    - globale_specificatie.md: fix servo/scan doc typos, mark GPIO table
    as verified against the KiCad V1.2 netlist, list external driver
    dependencies.
    - te doen.md: point GY9250 calibration docs at
    tests/test_gy9250_auto_calibrate.py and config.json, note the
    ldr_scan/ultrasoon PIO-block conflict is resolved, and correct the
    backup-file naming.
2026-07-27 Revise LDR-scan algorithm spec; add hardware CAD/PCB, README, webserver test
    - globale_specificatie.md + te doen.md: herzien LDR-scan-algoritme
    (370°-scan zonder pre-roll, piek op A≈B-kruispunt, kortste weg terug,
    closed-loop uitlijnen via null-seek op A−B tegen stepper-slip)
    - hardware/KiCAD: schema, PCB, PDF, iBOM en board-render (V1.2)
    - hardware/FreeCAD: assembly_all.step
    - README.md: projectbeschrijving
    - tests/test_webserver.py: webserver-test
    - kleine updates in stepper.py en gpio_pinout.md
    [DIY car 2.kicad_pcb, DIY car 2.kicad_sch, assembly_all.step]
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2026-08-05 Add stepper ramp (PIO/DMA), beam-axis positioning and gripper geometry
    Stepper ramp via PIO + DMA (lib/stepper/stepper_ramp.py)
    - Each FIFO word encodes a whole segment (repeat, delay) instead of one step,
    so a 256-segment S-curve ramp fits in 1 kB instead of 36 kB. A 50 cm move
    without steering is 513 words in a single DMA transfer: zero CPU overhead
    and one IRQ, matching the old fire-and-forget behaviour but with a ramp.
    - The original problem was loss of synchronism, not torque: commanding a
    speed directly asks the rotor to reach it within one 78 us microstep.
    Torque budget shows a factor 8 margin at VREF 1.0 V, so stealthChop and
    the current setting are fine.
    - Fixed a seriou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
    [test_ldr_beam.py, test_stepper_ramp_math.py]
2026-08-05 Match LDR code to the new 1 kOhm pull-ups; fix WHEEL_BASE_CM
    R29/R30 have been changed from 10 kOhm to 1 kOhm, so the code constants had
    to follow. Leaving LDR_R_FIXED_OHM at 10000 would have scaled every
    resistance by 10 without anything failing.
    - LDR_R_FIXED_OHM 10000 -> 1000. With a 100-200 Ohm LDR the old value used
    0.97 % of the ADC scale (~40 real 12-bit codes); 1 kOhm gives 7.6 %
    (4965 codes), a factor 7.8. The beam-axis measurement needs to resolve a
    Q decline of ~34 LSB, which was not possible with 10 kOhm.
    - LDR_R_MIN_OHM 60 -> 20. At 60 the percent scale clipped to 100 % close to
    the source, leaving the final positioning phase without information.
    - LDR_R_MAX_OHM unchang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
2026-09-17 Reorganize EN translations, add stepper ramp variants, fix LDR pull-up/noise
    - Move English translations from root into english translations/,
    including per-module translated Python copies of lib/ and tests/
    - Add lib/stepper/stepper_ramp_v2.py (DMA completion-IRQ variant) and
    lib/stepper/stepper_rmp.py (drop-in ramp replacement for stepper.py
    without sensor/course-correction code), plus tests/test_laser.py
    - Revert LDR_R_FIXED_OHM to 10k (R29/R30 pull-ups moved back to 10 kOhm
    with the new, brighter light source) and update dependent docs/checks
    - Average LDR ADC reads over 10 samples spaced 1ms apart in test_ldr.py,
    test_ldr_beam.py and measure_now(), to cancel 100Hz mains ripple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
    [test_all_en.py, test_data_logging_en.py, test_gripper_geometry_en.py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]
2026-10-19 ICM-20948 als vervanger GY9250, LDR-machtscorrectie en 4,7k pull-up
    - Nieuwe driver lib/ICM20948/icm20948.py (ICM20948 + AK09916), API gelijk
    aan de Tuupola MPU9250-driver; magnetometerassen uitgelijnd op accel/gyro
    - Basic/fusion/kalibratiescripts en tests hernoemd naar ICM20948;
    i2c-scan herkent ook 6-assige namaak (ICM-20648/20649, MPU-6500)
    - LDR: vaste LDR_GAIN_B vervangen door machtscorrectie B->A uit
    Meting_LDR_afstand_hoek.md, R_FIXED 4,7 kOhm, R_MAX 1 MOhm, nieuw
    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
2026-10-20 LDR pull-up is 47 kOhm (niet 4,7 kOhm): constanten en documentatie aangepast
    - LDR_R_FIXED_OHM 47 000, LDR_B_LN_C -0,6005 (gamma ongewijzigd)
    - Procentschaal LDR_R_MIN 100 Ohm, LDR_R_MAX 5 MOhm voor het nieuwe bereik
    - config.json "ldr", test_ldr_beam, pinouts en specificatie bijgewerkt
    - Meting_LDR_afstand_hoek.md: weerstandstabel herberekend, vergelijking
    47 kOhm tegenover 200 kOhm toegevoegd
2026-10-21 ICM-20948 in gebruik genomen: gyroteken en magnetometerkalibratie
    - GYRO_Z_SIGN = -1 (stepper_ramp, stepper_ramp_v2): gemeten met de
    ingebouwde ICM-20948, rechtsom draaien geeft gz < 0 (Z-as omhoog).
    - Magnetometerkalibratie in config.json, sectie "icm20948"
    (|B| 46-48 uT, inclinatie 66 graden, kompas 91 graden bij neus naar oost).
    - icm20948.load_mag_calibration() leest die sectie; basic/fusion-scripts
    en tests gebruiken hem in plaats van voorbeeldwaarden.
    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
2026-10-21 test_ldr: laser tijdens de meting 100% aan, uit bij stoppen
    GPIO15 als digitale uitgang (geen 50 Hz-PWM die in de LDR-meting
    doorkomt); laserstatus op OLED en in de uitvoer.
2026-10-21 LDR-scan: 1 kHz ringgemiddelde over 10 ms, plus kleinere correcties
    LDR-scan (ldr_scan_isr.py):
    - PIO SM8 geeft een vaste 1 kHz-tick; per tick een sample van A, B en
    de stepperpositie in een ringbuffer van 10, met lopende sommen.
    10 x 1 ms middelt de 100 Hz-rimpel van de 230V-ledlamp weg.
    - De gemiddelde positie van hetzelfde venster wordt aan het LDR-gemiddelde
    gekoppeld, zodat de ~4,5 ms groepsvertraging geen hoekfout wordt.
    - Decimatie naar ~3 scanpunten per graad; optionele ISR-tijdmeting
    (enable_irq_timing / irq_timing_stats).
    - 370 graden-scan zonder pre-roll; test_all.py aangepast aan de nieuwe
    scan()-signatuur.
    Overig:
    - servo_crl: opampgain 13 (1 + 47k/3,9k) en stroomform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
2026-10-21 Stepperpositie 500x sneller uitlezen; LDR-ISR-jittermeting
    - stepper, stepper_ramp, stepper_ramp_v2, stepper_rmp: PIO-instructies voor
    sm.exec() vooraf gecodeerd (asm_pio_encode) en teller via get(buf) in een
    signed array. pio_pos1()/pulses() ging van ~11,8 ms en 231 bytes naar
    24-36 us zonder allocatie. De 1 kHz-LDR-ISR (die de positie leest) haalde
    daardoor maar ~80 Hz; nu 9328 aanroepen in 9,3 s, gem. 121 us (12% CPU).
    - stepper.py: opstart-init van de tellers gebruikte "mov(y, 0xFFFFFFFF)",
    geen geldige PIO-instructie; y bleef 0 en pio_pos1() gaf 4294967295 tot de
    eerste reset_PIO_distance(). Nu put/pull/mov(y, osr) zoals de reset.
    - ldr_scan_isr: irq_timing_stats() geeft ook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
2026-10-21 Effectieve spoorbreedte 11,26 cm (gyro-gemeten)
    Een gecommandeerde 360°-rotatie (links) draaide volgens de ICM-20948-gyro
    434,9° (kompas ~420°): het ASA-frame zakt onder accu en motoren door,
    waardoor de banden op de binnenrand van het loopvlak lopen.
    - TRACK_WIDTH_EFF = 11,26 cm (= 13,6 x 360 / 434,9) in stepper,
    stepper_ramp, stepper_ramp_v2 en stepper_rmp; STEPS_PER_DEG rekent
    daarmee. TRACK_WIDTH = 13,6 blijft als geometrische referentie.
    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
2026-10-21 LDR-scan: CSV-schrijffout door heapversnippering opgelost
    _postprocess_to_percent() maakte vier lijsten van ~1100 floats, elk een
    los heap-object van 16 bytes tussen de scan-rommel. Na een scan was het
    grootste vrije blok daardoor 1,2 kB (bij 140 kB vrij) en faalde open()
    voor de CSV, die 1148 bytes aaneengesloten nodig heeft. Nu array('f'):
    één blok per reeks; grootste vrije blok na postprocess 186 kB.
2026-10-21 LDR-scan: doordraaien naar de lamp en correctie per draairichting
    - RETURN_FORWARD_ONLY = True: na de scan doordraaien in scanrichting in
    plaats van de kortste weg; een richtingswissel laat het zwenkwiel
    omklappen (ruk en slip).
    - ROT_SCALE_L = 360/369,95, ROT_SCALE_R = 1,0: stepper.rotate() 360° gaf
    rechtsom 360,0° en linksom 370,1°/369,8° op de gyro (laserstip 8 cm
    verder op 50 cm). _deg_to_distance_cm() en de tijdschatting rekenen per
    richting.
    - Verificatie (scan links, lamp op ~90°): doordraaien 82,9° gevraagd,
    82,92° gemeten; null-seek direct binnen de deadband (diff -0,025);
    eindkoers 89,0°; CSV geschreven.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
2026-10-21 stepper_ramp: STEP-puls 733 ns i.p.v. 200 ns (TMC2209 miste pulsen)
    rotate_deg(+90) draaide volgens de ICM-20948-gyro maar 54,4°, terwijl de
    PIO-teller (die de eigen STEP-pin leest) alle 5927 pulsen telde: de
    TMC2209 miste ~40% van de pulsen van 3 cycles (200 ns). Nu 11 cycles
    (733 ns, zoals stepper.py), verdeeld over mov[7] + nop[2] omdat één
    instructie met side-set maximaal [7] heeft. CYCLES_FIXED 5 -> 13, zodat
    de stapfrequentie gelijk blijft. Resultaat: 90,8°.
    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
2026-10-21 stepper_ramp: rotate_deg_gyro() - draaien gestuurd op de gyro
    rotate_deg() op stappen gaf voor 360° op gladde vloer 311° (rechtsom na
    een linksom-beweging: zwenkwiel haakt bij omklappen) tot 370° (linksom),
    op een ruwe mat 335° in beide richtingen. De stappenhoek hangt dus af van
    ondergrond en draairichting.
    rotate_deg_gyro() start rotate_deg() met 50% overmaat, integreert de gyro,
    leert onderweg k = gyrohoek/stappenhoek en roept brake() aan zodra de
    resthoek gelijk is aan de remhoek x k. Daarna langzame correcties
    (2 cm/s, stop met halt() op de gyro) tot +/-0,5°.
    Getest op gladde vloer: +360° fout 0,33° (k 1,004), -360° fout 0,38°
    (k 1,032), elk met één correctie; laser 3 mm re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
2026-10-22 LDR-scan op stepper_ramp; gewichtsverdeling in de specificatie
    - ldr_scan_isr.scan() gebruikt stepper_ramp i.p.v. stepper.py: zachte
    op- en afremramp (minder slip bij het omklappen van het zwenkwiel) en
    733 ns STEP-pulsen. _rotate_degrees() gebruikt rotate() met dezelfde
    graden->cm-omrekening als de scan (niet rotate_deg()), zodat het
    doordraaien naar de lamp stappen-consistent blijft.
    - test_all.py: stepper_ramp, sm0/sm1.active() -> busy().
    - Verificatie (scan links, lamp op ~90°): scan 368,6° (gyro), null-seek
    direct binnen de deadband (0,009), eindkoers 88,8°, laser ~1 mm naast
    de lamp op 50 cm.
    - Specificatie: wieldrukken 0,55/0,55 kg, zwenkwiel 0,50 kg op 150 mm
    achter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
2026-10-22 Magnetometerkalibratie voor de nieuwe ICM-20948-module; kompas geparkeerd
    De eerste module is defect geraakt bij het solderen van de INT-draad
    (GP7, data-ready geverifieerd: 229 Hz). Handkalibratie van de nieuwe
    module: |B| 49,5 uT, spreiding 7%.
    Een vloerronde met gyro-referentie (zonder USB-kabel) gaf toch
    +/-15-20 graden koersfout: de sensor zit naast de accu (stalen cellen,
    accustroom) en zwaait bij draaien op de plaats over een cirkel van
    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
2026-10-22 test_mag_stroomstoring: magnetische storing door motorstroom meten (drivers uit / houdstroom / draaiend)
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2026-11-01 ultrasoon.py: factor-2-bug in de afstandsmeting gefixt
    De COUNT_HIGH/WAIT_RISE-tellussen in usonic_pio() kosten 2 PIO-cycli per
    aftelling, dus bij PIO_FREQ_HZ=2MHz is 1 aftelling 1us, niet 0,5us zoals
    _PIO_SCALE aannam. Daardoor kwam read_cm()/read_us() structureel ~2x te laag
    uit (gebruiker merkte: 10cm gemeten was in werkelijkheid 20cm) en was de
    werkelijke timeout 2x langer dan TIMEOUT_US. Verklaart ook achteraf de eerder
    mislukte ultrasoon-gebaseerde WHEEL_CIRC-poging (2026-11-01, destijds
    toegeschreven aan de omgeving). Bevestigd op hardware na de fix: 20,8cm
    gemeten, meetlint klopte exact.
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
